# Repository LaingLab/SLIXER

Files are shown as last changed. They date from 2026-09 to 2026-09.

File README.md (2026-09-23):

<div align="center">

# Slixer

**A browser workbench for the SO-101 robot arm**

See it, program it, and let the camera tell it when.






[**Quick start**](#quick-start) ·
[**First run**](slixer/FIRST_RUN.md) ·
[**User guide**](slixer/README.md) ·
[**Vision**](slixer/VISION.md)

Slixer's 3D view of the arm beside the real SO-101, moving together

</div>

---

Slixer runs on a PC beside an [SO-101](https://github.com/TheRobotStudio/SO-ARM100) arm and serves one page to
a browser. On it:

- **A live 3D model of the arm**, built from the SO-101's own CAD, that mirrors the real arm as you move it.
- **Programs**, recorded by demonstration (move the leader arm, press R) or posed by dragging the model, then
  rehearsed on a virtual arm and played smoothly on the real one.
- **Your bench in 3D.** Import STL files of fixtures and labware, place them where they really are, and
  double-click one to send the gripper to it.
- **The camera**, with [Ultralytics](https://github.com/ultralytics/ultralytics) YOLO detecting and outlining
  what it sees on your GPU, including open-vocabulary YOLOE ("well plate, pipette tip") that needs no
  training. A program can wait until the camera sees something. Slixer also collects training pictures, with
  draft labels, for teaching a model your own things.

Three modes keep it clear what the model means: **Watch** mirrors the arm and never sends anything, **Plan**
is a virtual arm to rehearse on, and **Drive** moves the real one, speed-limited, with **STOP** (or Esc)
always a keypress away.

## How it fits together

```
 leader arm ──radio──▶ follower arm ◀──Wi-Fi──▶ PC running Slixer ◀──▶ browser
  (XIAO ESP32-C3)       (XIAO ESP32-C3)              ▲
                                                     │ camera frames
                                          Raspberry Pi + USB camera
```

The two arms teleoperate each other with no computer at all, over their own radio link. Slixer joins over
Wi-Fi: it watches the follower, and can drive it. It doesn't use lerobot's USB connection; the arms run the
firmware in this repository.

## Prerequisites

1. [uv](https://docs.astral.sh/uv/getting-started/installation/), which manages Python and the environment:
   `curl -LsSf https://astral.sh/uv/install.sh | sh`
2. **The arms**: an SO-101 leader and follower, each on a Seeed *Bus Servo Driver Board for XIAO* with a
   XIAO ESP32-C3, flashed from `so101_leader/` and `so101_follower/`. See the
   [firmware guide](so101_leader/README.md).
3. **Linux or WSL2.** Under WSL2, turn on mirrored networking so the arm's packets reach it (the firmware
   guide says how).
4. For the camera: a Raspberry Pi with a USB camera, running `pi/camera_stream.py`. For YOLO: an NVIDIA GPU
   with a recent driver (CUDA 13). Without one it runs on the CPU, slowly.

## Quick start

```bash
git clone https://github.com/LaingLab/SLIXER.git
cd SLIXER
uv sync --extra vision      # or plain `uv sync` without YOLO: the extra brings PyTorch, a few GB
uv run slixer/run.py        # then open http://localhost:8000
```

On the camera Pi: `uv run pi/camera_stream.py`. Then tell Slixer where it is, once:
`uv run slixer/run.py --camera <the Pi's address>`.

[**FIRST_RUN.md**](slixer/FIRST_RUN.md) walks through the first session in order: flashing, lining the
model up with your arm, a first program, and the camera.

> **Keep `--extra vision` on every `uv sync`.** A plain `uv sync` makes the environment match the lockfile
> exactly, so it removes PyTorch and Ultralytics again. `uv run` never removes anything.

## Documentation

| | |
| --- | --- |
| [slixer/FIRST_RUN.md](slixer/FIRST_RUN.md) | the first session, step by step |
| [slixer/README.md](slixer/README.md) | the user guide: modes, programs, parts, camera, lining up |
| [slixer/VISION.md](slixer/VISION.md) | YOLO models, open-vocabulary detection, and training your own |
| [so101_leader/README.md](so101_leader/README.md) | the arms' firmware: wiring, flashing, Wi-Fi, calibration |
| [CHANGELOG.md](CHANGELOG.md) | what's changed |

## What's in here

| folder | |
| --- | --- |
| `slixer/` | the app: a FastAPI server and the page it serves (three.js) |
| `so101_leader/`, `so101_follower/` | firmware for the two arms' XIAO ESP32-C3 boards |
| `pc/` | Python for your own code: `so101_link.py` talks to the arm, `camera_client.py` receives the camera |
| `pi/` | the camera streamer, for the Raspberry Pi |

## Safety

Slixer moves a robot. It's a beta, so go gently the first time it drives your arm.

- **STOP** (or **Esc**, which works even while you're typing) ends a program, drops anything still on its
  way, and holds the arm where it actually is. Switching to **Watch**, or closing every Slixer tab, lets go
  of it; switching to **Plan** keeps holding it.
- In **Drive**, moves are speed-limited and held to the range the arm was calibrated over. Drive waits for
  a follower that says it's ready, and a program waits for the arm: it pauses while the arm is out of
  touch, and stops, holding it, if the arm can't get where it's sent.
- **If the page loses Slixer**, it says so, and until it reconnects it can't send anything, STOP included.
  A STOP pressed meanwhile is sent the moment it's back; if the arm must stop sooner, switch off its power.
- **Parts are drawn, not felt.** The arm doesn't know an imported part is there, and will drive through it.
- **The page is served to this PC only**, unless you start it with `--host 0.0.0.0`, and only Slixer's own
  page can drive the arm, not another website open in the same browser. The arm's Wi-Fi link has no
  password of its own: anything on the same network can send it poses. Keep the arm on a network you
  trust. See [SECURITY.md](SECURITY.md).

## Development

```bash
uv run pytest               # about 160 tests, two minutes, no hardware needed
```

The tests run against an imitation follower that runs the firmware's own logic (`slixer/tests/fake_follower.py`)
and an imitation camera (`slixer/tests/fake_camera.py`), on ports the real arm never uses. The YOLO tests run
when the vision extra is installed and the models are downloaded, and are skipped otherwise.

## Licence and credits

MIT, © 2026 Laing Lab. See [LICENSE](LICENSE).

- The SO-101 model (URDF and meshes) is [TheRobotStudio/SO-ARM100](https://github.com/TheRobotStudio/SO-ARM100),
  under the Apache License 2.0: see [slixer/assets/so101/](slixer/assets/so101/).
- [three.js](https://threejs.org), vendored in `slixer/web/vendor/`, is MIT.
- The vision extra installs [Ultralytics](https://github.com/ultralytics/ultralytics), which is AGPL-3.0 (as are
  its YOLO weights). It isn't part of this repository, and the rest of Slixer runs without it.

If Slixer helps your research, please cite it: see [CITATION.cff](CITATION.cff).

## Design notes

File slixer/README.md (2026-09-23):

# Slixer

A 3D model of your SO-101, the camera beside it, and a place to write what it should do — in one page in
a browser. The model is the real SO-101 geometry; its six joints are your six servos.

```bash
uv run slixer/run.py                          # then open http://localhost:8000
uv run slixer/run.py --camera 192.168.1.50    # tell it where the camera Pi is (remembered after that)
```

`./slixer/start.sh` does the same from any folder. New here? Read [FIRST_RUN.md](FIRST_RUN.md): it walks
through the first session in order.

## Three modes

The switch at the top right decides what the model on screen *means*, and the edge of the view is
coloured so you can't mistake which one you're in.

| mode | the model is | sends to the arm | edge |
| --- | --- | --- | --- |
| **Watch** | a mirror of the real arm | never | none |
| **Plan** | a virtual arm you pose and rehearse on | never | blue |
| **Drive** | what you are telling the real arm | yes | orange |

**Watch** is where it starts, and where you teach by demonstration: move the leader by hand, the model
follows, press **record pose**. Nothing you do in Watch moves anything.

**Plan** is where programs get written. The model comes loose from the arm: drag the orange handle,
use the sliders, double-click a part, play a program — the real arm stays exactly where it is, drawn as a
blue ghost so you can see it. Coming from Drive, Slixer goes on holding it there until you switch to Watch.
Plans are still held to the arm's own calibrated joint limits.

**Drive** moves the real arm. Switching in never makes it jump (it starts from where the arm is),
commands walk at up to 90°/s rather than snapping, and everything is held to the range the arm was
calibrated over. **STOP** or **Esc** — which works even while you're typing — ends the program, drops
any move still on its way, and **holds the arm where it actually is**, still in Drive. Switching to
**Watch** is how you let go of it: the arm then freezes, or, with the leader on, glides back to the
leader. Closing every Slixer tab lets go too. Dragging the orange handle only ever bends the arm on from
the pose it's in — it never refolds it — and lining the model up in Setup is refused while driving, since
it would move the arm.

Drive waits for the follower to say it's ready: not while it's checking itself after a fault, recording
its ranges, or without a calibration. If it stops taking poses while you drive, Slixer stops sending,
goes back to Watch, and says why. If the page loses its connection to Slixer, a banner says so: until it's
back, the page can't send anything, STOP included. A STOP pressed meanwhile is sent the moment it
reconnects, but if the arm must stop sooner, switch off its power.

## Programs

A program is a list of steps: **move**, **wait**, **gripper**, and **wait for** (until the camera sees
something). New steps go in after the selected one. Select a move and it's drawn in amber — see where it
goes without going there. Double-click a move (or press **go there**) to send the model there in Plan,
or the arm in Drive. **set to current pose** re-records a step. **▶ from here** plays from the selected
step. Programs save to `slixer/programs/` as readable JSON.

In Drive, a program waits for the real arm. A move is over when the arm has got there, not when the model
has, so the next step starts from where the arm really is. If the arm drops out of touch the program
pauses, and carries on smoothly once it's back; if the arm gets no closer for 3 seconds (something in its
way, or a pose it can't reach), the program stops and holds the arm where it is.

**Moves store the arm's own numbers** — five joint angles in degrees from the middle of each joint's
calibrated travel, plus the gripper in percent: the same numbers the leader prints on its serial port.
Not the 3D model's angles. That means re-lining the model up in Setup can never change what a saved
program does to the arm.

Keys: **R** records a pose from any tab. On the Program tab, **↑/↓** select, **Delete** removes a step.

## Parts

The **Scene** tab imports STL files — the bench, a fixture, the box you pick from. Put each where the real
one sits (drag it, or type millimetres; **sit on the floor** drops it flat, whichever way it's turned).
Then, in Plan or Drive, **double-click any part's surface** and the gripper reaches for it, stopping a set
distance short along the surface — press R and that's a waypoint.

CAD and slicers export in millimetres; the model is in metres. Anything implausibly large is read as
millimetres and scaled, and the panel says so. **Parts are drawn, not felt**: the arm doesn't know they
exist and will drive straight through one.

## Camera and models

The Camera tab shows the Pi's stream exactly as it arrives. Give it the Pi's address once; it's
remembered. **camera** (top right of the view) floats it over the model; drag to move, pull the corner to
resize.

A YOLO model can run on the picture, on this PC's GPU, in a process of its own: everyday things,
**anything you type** (open-vocabulary YOLOE: "well plate, glove"), or a model you've trained on your own
things. What it finds is outlined on the picture, and a program's **wait for** step can wait for any of
those names. The Camera tab also collects training pictures, with draft labels, for training your own.
It needs the vision extra (`uv sync --extra vision`). All of it is in **[VISION.md](VISION.md)**.

## Setup: lining the model up

The URDF has its own zero for each joint, and which way your servos count depends on how they were
assembled — so the first time, the model may turn some joints the wrong way. The Setup tab shows each
joint's reading from the arm beside the model's, live. Move a joint by hand: **flip** any that turn the
wrong way, **offset** any that sit at an angle, then **save**. Changes show at once but are only kept
when you press save.

## The leader arm and Drive

The leader can stay powered while Slixer drives. Slixer's poses carry a marker saying they come from a
program, and the follower gives them the arm while they keep coming, holding the leader back. A quarter
of a second after Slixer stops sending (you switch to Watch), the arm glides back to the leader. So you
can teach with the leader, play, and carry on teaching, without powering anything down. It follows that
grabbing the leader doesn't take over from a running program: **STOP** does.

That needs the follower firmware in this repository (protocol 2, which the follower reports in its
status). With older firmware, the leader and Slixer fight over the arm, so power the leader down before
Drive. Either way, if the arm stops following what Slixer tells it, a red banner says so.

## On the network

The default is localhost only: this page can move a robot. `--host 0.0.0.0` opens it to the lab, with no
login. Either way, only Slixer's own page can drive the arm. A browser will connect to Slixer for any
website that asks, so Slixer refuses a connection from any other site, and any request addressed to a
name it doesn't answer to. IP addresses and this PC's own name work; `--allow-host NAME` adds another,
such as a DNS alias.

The arm's own link is plain UDP on port 50101 with no password: anything on the same network can send it
poses, so keep it on a network you trust. Under WSL the arm's UDP only arrives with mirrored networking on.

## Tests

```bash
uv run pytest     # ~160 tests, about two minutes, no hardware
```

They run against `tests/fake_follower.py`, which runs the follower firmware's own logic (both the old and
the new), and `tests/fake_camera.py`, in a throwaway data folder on ports the real arm never uses. The
YOLO tests run when the vision extra is installed and the models are downloaded, and are skipped
otherwise. `--data DIR` and `--arm-port N` do the same for a hands-on session with no arm:

```bash
uv run slixer/tests/fake_follower.py --listen 50198 --report-to 50199 &
uv run slixer/tests/fake_camera.py --port 50113 &
uv run slixer/run.py --arm-port 50199 --camera 127.0.0.1 --camera-port 50113 --port 8001 --data /tmp/slixer-try
```

## The pieces

| file | what it does |
| --- | --- |
| `run.py`, `start.sh` | start everything |
| `server.py` | the page, the camera, the live link |
| `session.py` | the only thing that sends to the arm: modes, one loop, all the safety rules |
| `kinematics.py` | reads the URDF; forward kinematics and the IK behind dragging and reaching |
| `mapping.py` | model angles ↔ the arm's own numbers |
| `program.py` | steps, and how a move is played out over time |
| `scene.py` | imported parts |
| `vision.py` | the model's settings → what a program can wait for |
| `detection.py`, `yolo_worker.py` | the YOLO model, in a process of its own |
| `dataset.py`, `train.py` | training pictures; training your own model |
| `settings.py`, `paths.py`, `version.py` | what's remembered, and where; which version this is |
| `web/` | the page; `three.js` is vendored so it works without internet |

The model is from [TheRobotStudio/SO-ARM100](https://github.com/TheRobotStudio/SO-ARM100)
(`Simulation/SO101`, Apache-2.0: see `assets/so101/`); `bake_meshes.py` turns its STLs into what the page
loads.

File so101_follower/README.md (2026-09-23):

# SO-101 wireless teleoperation, two XIAO ESP32-C3 boards

The leader arm's XIAO reads its six joints 50 times a second and broadcasts them by radio (ESP-NOW). The
follower arm's XIAO drives its servos to match. No computer, no network, no pairing: the two boards find
each other by themselves, and either can be restarted at any time.

Each XIAO plugs into its arm's Seeed *Bus Servo Driver Board for XIAO*, which powers it from the arm's own
supply. Calibration is read from the servos at every power-up (lerobot-calibrate stores it there), so
recalibrating never needs a re-flash. Joint mapping matches `lerobot-teleoperate` to within one encoder step.

## 1. Calibrate first

Once a board is switched to XIAO mode, lerobot on the PC can't reach that arm until you switch it back
(section 9). Do any `lerobot-calibrate` runs before converting. For the "middle" step put every joint
mid-range, and push each joint all the way to both stops during the sweep.

## 2. Switch both driver boards to XIAO mode

On each board:

1. Pull off the 2-pin **jumper cap** on the front.
2. On the back, open the solder jumpers **JP1** and **JP2**: no continuity between each pair of pads.
   (Early boards have two small resistors, R12 and R18, there instead: remove them.)
3. Solder headers to the XIAO and plug it in, USB-C end matching the outline printed on the board.

In USB mode the board's USB chip sits on the same D6/D7 wires as the XIAO, and the two fight over the line.

## 3. Flash

Arduino IDE 2, **Tools > Board > esp32 > XIAO_ESP32C3**, USB CDC On Boot enabled (the default).

- Open `so101_leader/so101_leader.ino`, select the leader's XIAO port, Upload.
- Open `so101_follower/so101_follower.ino`, select the other XIAO port, Upload.

The two sketches share the same headers; the folder decides which board does what. Built and checked with
esp32 core 3.3.8 and 3.3.12. For Wi-Fi, set it up first (section 7); without it the boards use their direct
radio link only, which is all teleoperation needs.

## 4. Use

Power both arms, in any order. Within a second or two the follower glides to the leader's pose and then
tracks it. Nothing moves until the follower has checked its own arm and is receiving the leader's pose.

The follower has no built-in LED. Wire one from **D10** through a ~330 ohm resistor to GND for status:

| LED | Meaning |
|---|---|
| slow blink (1 Hz) | arm checked, waiting for the leader |
| medium blink | gliding to the leader's pose |
| steady on | following |
| fast blink | leader data stopped: holding its pose, torque on |
| repeating blink count | a problem: 1 = no reply from a servo, 2 = no usable calibration, 3 = a joint outside its range, 4 = torque refused |

The follower holds its pose while the leader is off. Switch the follower off first, or support the arm.

Wrist roll is the one joint that can reach the encoder's wrap point: past about half a turn from its
calibration orientation the follower stops at its limit instead of spinning round.

## 5. Watching what happens

Open the Serial Monitor on the **leader** (any baud rate). It prints its own state and the follower's,
which the follower reports over the radio every 2 seconds:

```
[leader] follower reporting, 1500 poses sent, 15 follower reports, 0 read failures | deg: ...
[follower] following | 98 poses received
```

This matters because the follower's board feeds its XIAO from the arm's supply, which fights the PC's USB:
with 12 V applied, the follower's own USB port usually won't enumerate. The leader's board runs from 5 V and
doesn't have that problem.

## 6. Re-recording a joint's travel without a PC

lerobot-calibrate writes each joint's travel into the servos, and the servos enforce it: a joint that was
swept too little during calibration can't move beyond what was recorded. You can redo the sweep from the
**leader's** Serial Monitor, with no soldering and no lerobot. Homing offsets (the joint zero points) are
left alone, so this fixes a bad range without redoing a full calibration.

| Key | Effect |
|---|---|
| `h` / `H` | centre the arm on the pose it is in now (leader / follower) |
| `r` / `s` | start / save a sweep of the **leader's** arm |
| `R` / `S` | the same for the **follower's** arm, sent over the radio |
| `x` / `X` | cancel |
| `?` | list the keys |

**Centring (`h`/`H`) is only needed when a joint's travel crosses the encoder's 0/4095 seam**, which shows
up as that joint sweeping nearly 4095 steps while the others sweep about 2200. Such a sweep is refused when
you save it, and a range like that already in a servo is reported at start-up (see Troubleshooting), rather
than aiming the joint at a middle it can't reach. Hold every joint near the middle of its travel, press
`h`, then sweep and save. Centring opens the limits right up until you save a
sweep, so if you power off in between, the arm reports no usable calibration and you simply redo it.

The servos only keep new ranges through a power cycle if their EEPROM write-lock is clear, so saving
clears it, writes, reads the values back, and locks again. Power-cycle once afterwards to confirm: the arm
should still report `arm ready`.

Type the key and press Enter. **Support the follower before `H` or `R`**: both switch its torque off
first, so it goes limp (the log says `torque off: support the arm`). While recording, that arm's torque
stays off and the leader stops sending poses, so the follower holds still instead of mirroring the sweep.
Move **every** joint to both of its stops, then save. A sweep that missed a joint, or crossed the seam, is
refused rather than saved, and the recording carries on: sweep again and save, or cancel. After a save the
arm re-checks itself, so the log tells you whether it took.

## 7. Putting the arms on Wi-Fi (for a PC to drive them)

In **both** sketch folders, copy `wifi_config.example.h` to `wifi_config.h`, fill in your network's name
and password, and re-flash. (`wifi_config.h` is ignored by git, so the password stays on your machine.)
Each board then prints `link up (radio + wifi)` and carries the same packets over both paths: the direct
radio link between the boards, and UDP for anything else on the network. Without `wifi_config.h`, or
with the name left empty, the boards use the radio only.

With Wi-Fi up, a PC anywhere the network reaches can watch the arm and drive it -- with
[Slixer](../slixer/README.md), or from your own code using `pc/so101_link.py`:

```
python pc/so101_link.py            # watch the arm: state, joint angles, gripper
python pc/so101_link.py --hold     # hold it where it is, proving the control path
```

No addresses to configure: the arm announces itself once a second and the script learns where it is.
Targets are joint angles measured from the middle of each joint's own travel, the same units the leader
sends. A program's poses are marked as coming from a program, and while they keep coming the follower
holds the leader back; a quarter of a second after the program stops, the leader has the arm again. So
grabbing the leader does **not** take over from a running program -- stopping the program does. With no
leader powered, stopping leaves the arm frozen in place rather than limp.

Press **W** in either board's Serial Monitor to list the networks it can hear, with their signal strength:
the quickest way to tell a wrong password from a board that can't hear the network at all.

**Under WSL**, add this to `C:\Users\<you>\.wslconfig` and run `wsl --shutdown`, otherwise packets from
the arm can't reach it (it also detaches any usbipd devices, so re-attach them afterwards):

```
[wsl2]
networkingMode=mirrored
```

Running the script from Windows instead needs no configuration at all.

## 8. Radio range

The XIAO ESP32-C3 depends on the **external antenna** that came in its box: plug one into the U.FL socket
on each board, and keep it clear of the arm's metalwork rather than lying against a bracket. Without it,
range is poor.

The firmware sends at the chip's maximum power and uses Espressif's Long Range PHY at 250 kbps, which is
far more robust than ordinary Wi-Fi rates. **Both boards must run the same firmware version for this** — a
board in long-range mode and one without it cannot hear each other at all.

Still short? Change `kFallbackChannel` in `link.h` (1, 6 and 11 are the usual choices), re-flash both, and
pick one your Wi-Fi router isn't sitting on.

## 9. Back to lerobot on the PC

Unplug the XIAO, re-bridge JP1 and JP2 with solder, and refit the jumper cap. Plug the XIAO back in only
after re-opening them.

## Troubleshooting

- **`no reply from servo N`**: arm power, board not in XIAO mode (JP1/JP2, jumper cap), XIAO orientation, or
  the 3-pin servo lead. To rule out the XIAO itself, take it off the board, join **D6 to D7** with a wire,
  power it by USB and type **`L`** in its Serial Monitor: it sends six bytes and checks they come back.
- **`outside its calibrated range`**: move that joint by hand toward the middle; it re-checks every second.
- **`no usable calibration in servo N`**: that joint's recorded travel is too small to use. Re-record it
  with the keys in section 6, or recalibrate with lerobot.
- **`... has no range yet (limits 0-4095)`**: the servo's limits are wide open, as centring leaves them.
  Record a range with the keys in section 6, or recalibrate with lerobot.
- **`... is nearly a full turn: it crosses the encoder seam`**: that joint's range was recorded across the
  0/4095 seam, so its middle is somewhere it can't reach. Centre (`h`/`H`) and record it again (section 6).
- **The IDE offers "Ozobot circuit kit" instead of the XIAO**: its board entry claims the same generic
  Espressif USB id, so auto-detect matches it first. Select **Tools > Board > esp32 > XIAO_ESP32C3** by
  hand and ignore the mismatch warning; the sketch refuses to build for the wrong chip anyway.
- **Nothing from the follower in the leader's log**: check the follower has power, is flashed with
  `so101_follower`, and that both boards print `radio up` at start-up.
- **The follower joins Wi-Fi with the arm's 12 V unplugged, but not with it on**: noise from the servo
  supply is drowning its Wi-Fi receiver. Press **W**: hearing *no* networks at all with the 12 V on, and
  yours with it off, confirms it. (The board-to-board radio keeps working, because its long-range mode is
  far more robust than Wi-Fi.) Move the antenna away from the servo board and its power wiring, add
  decoupling at the XIAO or ferrites on the power leads, or try a quieter supply.

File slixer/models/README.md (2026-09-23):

# Models

YOLO weights live here. None are in the repository: the stock ones (`yolo26s-seg.pt` and the rest) download
here the first time they're picked in the Camera tab, and `slixer/train.py` copies models you train here too.
Any `.pt` file put here shows up in the Camera tab's list. See [VISION.md](../VISION.md).

The stock weights are Ultralytics', under the AGPL-3.0 (or an Ultralytics Enterprise licence).

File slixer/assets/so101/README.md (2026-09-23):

# The SO-101 model

`so101.urdf` is `Simulation/SO101/so101_new_calib.urdf` from
[TheRobotStudio/SO-ARM100](https://github.com/TheRobotStudio/SO-ARM100), unchanged apart from its name
(upstream commit `385e8d7c68e2`). The meshes Slixer shows, in `slixer/web/models/`, were made from that
model's STL files by `slixer/bake_meshes.py`: each link's meshes merged into one and simplified.

Both are the work of TheRobotStudio, used under the Apache License 2.0 (`LICENSE`, beside this file).

The original STLs aren't included: they're 16 MB, and only needed to re-bake the meshes. To do that, put
upstream's `Simulation/SO101/assets/` folder here as `assets/` and run `python slixer/bake_meshes.py`.

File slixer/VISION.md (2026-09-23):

# Vision: detecting and outlining things

Slixer can run Ultralytics YOLO models on the camera, on this PC's GPU. On an RTX 4090 that's about 14 ms
a picture for segmentation, so it keeps up with the camera with room to spare. What a model finds is
outlined on the picture, and its names count for a program's **wait for** steps.

Everything here is on the **Camera** tab.

## How it's set up

Ultralytics and PyTorch are an optional extra, because they're a few gigabytes:

```bash
uv sync --extra vision
```

Keep `--extra vision` on every `uv sync` after that: a plain `uv sync` makes the environment match the
lockfile exactly, which removes them again. On Linux, PyTorch comes as its CUDA 13 build, which needs a
recent NVIDIA driver; without a usable GPU the models run on the CPU, slowly.

The model runs in a **process of its own**, so the arm can't be affected. Slixer's control loop runs 50
times a second in the main process; a model loading, a slow picture, or a CUDA error in the model's
process can't delay it or crash it. If the model's process dies, the Camera tab says why and the arm
carries on.

Ultralytics asks for the full `opencv-python`. Slixer uses `opencv-python-headless` (the same OpenCV
without a desktop's GUI libraries), and the two can't be installed together without overwriting each
other's files, so `pyproject.toml` leaves the full one out. Ultralytics works the same with either.

To upgrade Ultralytics: `uv lock --upgrade-package ultralytics && uv sync --extra vision`. To run the
models in some other environment, point `SLIXER_VISION_PYTHON` at its Python.

Models live in `slixer/models/`; stock ones download there the first time they're picked. A model of your own
goes there too: copy in its `.pt` and reload the page. Each model runs at the picture size it was trained at,
so one trained at 1280 runs at 1280.

## Three kinds of model

| model | finds | when to use it |
| --- | --- | --- |
| `yolo26s-seg.pt` (n, s, m) | the 80 everyday COCO things — person, cup, bottle, … — outlined | trying things out |
| `yoloe-26s-seg.pt` | **whatever you type**: "well plate, pipette tip, glove" — outlined | your own things, today |
| `<yours>.pt` | exactly what you trained it on | once you've trained one |

`-seg` models outline what they find; the others only box it. The `yoloe-…-pf` model has a large built-in
vocabulary instead of being told what to look for.

A **semantic** model (one trained from `yolo26n-sem`, on the Ultralytics Platform say) marks areas rather than
things: it gives every pixel of the picture a class. Slixer outlines each patch of a class as a find, with its
box and its middle, so it's drawn and waited for like any other. A class map carries no confidence, so
**sure enough at** doesn't change what it marks; patches smaller than a speck are left out. Classification,
rotated-box (OBB) and depth models find nothing in the picture to outline, and are refused when picked.

**Start with YOLOE.** It finds things by name with no training at all: pick `yoloe-26s-seg.pt`, type what
to look for in the box, tick **run**. Whether it finds a 6-well plate well enough depends on the plate and
the light — try it. Where it's good enough, you're done; where it isn't, it still makes useful draft
labels for training your own model (below). Changing the words takes a moment, not a restart.

**sure enough at** is the confidence below which a find is ignored. Higher means fewer false alarms and
more misses.

## Teaching a model your own things

When a stock or open-vocabulary model isn't reliable enough, train one. The loop:

**1. Collect pictures** — Camera tab → *Training pictures*. Name the dataset (e.g. `plates`), then press
**capture** (or **C**), or set **every 2 s** and move things about. Each picture is saved exactly as the
camera sent it, with the arm's pose at that moment. With a model running and **draft labels** ticked,
what the model saw is saved as a first draft of the labels. An unchanged scene isn't saved twice.

Aim for a couple of hundred pictures to start, varied the way the arm will really see things: different
positions, angles, lighting, clutter, the gripper in shot, partly hidden objects, and a few with none of
your things in (they teach it what *isn't* there).

**2. Correct the labels** in an annotation tool. Outlines, not boxes, for a segmentation model.

- [CVAT](https://www.cvat.ai) or [Label Studio](https://labelstud.io) (both free; run locally or online),
  or [Roboflow](https://roboflow.com) (quickest to start).
- Import `slixer/datasets/<name>/images/` with the draft labels in `labels/` (YOLO format, class names
  in `classes.txt`), fix and finish them, and export as **YOLO / Ultralytics segmentation**.
- Put the exported `labels/` back over the dataset's `labels/`, and its class list in `classes.txt`
  (one name per line, in the same order as the class numbers) — or keep the tool's export whole and
  train from its `data.yaml` (next step).

Draft labels from a stock model use its names ("cup"); rename them to yours in the tool. YOLOE drafts
already carry the names you typed.

**3. Train.** On an RTX 4090, a few hundred pictures take minutes:

```bash
uv run slixer/train.py plates                          # a dataset Slixer collected
uv run slixer/train.py ~/Downloads/export/data.yaml    # or a tool's export
```

It splits the labelled pictures 80/20 into learning and checking, trains from `yolo26s-seg.pt`, and copies
the best result to `slixer/models/plates-<date>.pt`. `--model yolo26s.pt` trains a box-only model;
`--epochs` sets how long.

**4. Use it** — reload the Camera tab, pick `plates-<date>.pt`, tick **run**.

**5. Go round again.** Run your model while capturing more pictures: its drafts are now about your things,
so each round of correcting is faster, and the next model better.

## Using what it sees

- **In a program**: `+ wait for` → type or pick a name. The step waits until the model sees that name,
  or gives up after the time you set.
- **Where**: every find carries a box, a centre and (for `-seg`) an outline, all as fractions of the
  picture, in Slixer's state (`slixer.state.vision.found` in the browser console).

Not done yet: turning a position *in the picture* into a position *for the gripper*. That needs the
camera calibrated: its lens, and where it sits relative to the arm (on the wrist, where it points changes
as the arm moves). The arm's pose saved with every training picture is the start of that; it's the
natural next step once detection is reliable.

## If something's wrong

| the Camera tab says | because |
| --- | --- |
| *Models need the vision extra* | run `uv sync --extra vision`, then restart Slixer |
| *Loading … (the first time, it downloads)* | fetching the weights: a few seconds to a minute |
| *… finds things by name: type what to look for* | YOLOE needs words in the **look for** box |
| *Stopped: …* | the model process died; the reason follows, and `vision-worker.log` has the rest |
| *Stopped: it failed on 20 pictures in a row: …* | it loaded, but Slixer can't read what it returns; the reason follows, and `vision-worker.log` has the rest |
| *Stopped: … is a classification model* | it names a whole picture rather than finding things in it: train a detection or segmentation model |
| it runs but finds nothing | lower **sure enough at**; check the words (YOLOE) or the model |

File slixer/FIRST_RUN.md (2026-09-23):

# First run

In order. The first two steps need doing once; after that, starting Slixer is one command.

## 1. Flash both boards (once)

The [firmware guide](../so101_leader/README.md) covers the hardware side: calibrating the arms, switching
their driver boards to XIAO mode, and fitting the antennas. Then:

1. In **both** `so101_leader/` and `so101_follower/`, copy `wifi_config.example.h` to `wifi_config.h` and
   put your network's name and password in it. (`wifi_config.h` stays out of git.)
2. Open each sketch in the Arduino IDE 2 and upload it: `so101_follower` to the follower's XIAO,
   `so101_leader` to the leader's. Pick the board by hand each time, **Tools → Board → esp32 →
   XIAO_ESP32C3**: the IDE likes to guess "Ozobot circuit kit", which is the wrong chip.

Power both arms. The follower should glide to the leader's pose and follow it. The leader's Serial Monitor
shows both boards' state every two seconds, the follower's for example:

```
[follower] following on radio + wifi (192.168.1.135, -41 dBm) | 812 poses (0 stale ignored, 0 leader poses held back for a program) | goals: ...
```

If it says `radio only (...)` instead, the bracket says why. Press **W** in either board's Serial Monitor to
list the networks it can hear. A follower that hears *no* networks at all while the arm's 12 V supply is
on, but does with it off, is being drowned by supply noise: move its antenna away from the servo board and
its power wires.

## 2. Install and start

```bash
git clone https://github.com/LaingLab/SLIXER.git
cd SLIXER
uv sync --extra vision
```

On the camera Pi (with its own copy of the repository): `uv run pi/camera_stream.py`

On the PC:

```bash
uv run slixer/run.py --camera 192.168.1.50     # your Pi's address: only needed the first time
```

Open **http://localhost:8000**. Top left should read something like **following the leader arm** (or
**holding**) and **camera**. If the arm pill says **no arm on the network**, the follower isn't on Wi-Fi
(step 1), or this PC can't hear it: under WSL2, turn on mirrored networking (see the firmware guide), and
`uv run pc/so101_link.py` prints whatever arrives.

## 3. Line the model up (about five minutes, once)

**Setup** tab, in **Watch**. Move one joint of the leader at a time; the follower copies it, and the model
should too.

- A joint turning the **wrong way**: **flip**.
- Turning the right way but **sitting at an angle**: type an **offset** until it matches.
- **save**.

The **arm** column is the arm's own reading; the **model** column is the model's. Programs don't depend
on any of this (they store the arm's own numbers), so you can record programs before lining up if you
like, but dragging the gripper and reaching for parts need it right.

## 4. A first program, by demonstration

1. **Program** tab, **Watch** mode.
2. Move the leader to a pose. Press **R**. Move, **R**. Three or four poses.
3. **+ gripper** between them if you like. Select any move to see it in amber.
4. Switch to **Plan** and press **▶ play**: it rehearses on the virtual arm. The real one doesn't move.
5. Hand near **STOP** (or Esc). Switch to **Drive**, press **▶ play**. The follower runs it. **STOP**
   holds the arm where it is; switch to **Watch** to let go of it.
6. **save** it with a name.

You can leave the leader on: it's held back while Slixer drives, and has the arm back a quarter of a second
after you switch to Watch. If the arm stops following, a red banner says so, with the likely reason.

## 5. Things to try

- **Plan mode, orange handle**: drag the gripper around; the sliders pose each joint.
- **Scene**: drop in an STL of something on your bench, place it, then (in Plan) **double-click its
  surface**: the gripper goes there, 20 mm short. **R** records it. A part that comes in standing on its
  edge (exported Y-up) needs **lie flat**.
- **Camera → Model**: pick `yoloe-26s-seg.pt`, type what to look for ("well plate, pipette tip"), tick
  **run**: it outlines them with no training. Or `yolo26s-seg.pt` for everyday things. A program's
  **+ wait for** step can then wait for any of those names. [VISION.md](VISION.md) has the rest, including
  training a model on your own things.
- **camera** (top right of the 3D view) floats the picture over the model; drag it about, pull its corner.

## If something's wrong

| you see | likely because |
| --- | --- |
| a joint of the model turns the wrong way | not lined up yet: Setup, flip |
| red banner "the arm isn't following" | the leader is on and the follower has older firmware (flash it), or something is blocking the arm |
| arm pill "only the leader is on Wi-Fi" | the follower isn't on Wi-Fi; Drive is refused, since it couldn't hear you |
| Drive refused: "no arm to drive" | no follower reports reaching this PC |
| Drive refused: "the arm isn't ready" | the follower is checking itself after a fault, or recording ranges: the message says which |
| "stopped sending to the arm" | the follower stopped taking poses while you drove it; Drive again once it's ready |
| a program stops: "the arm didn't get there" | something is in the arm's way, or the pose is out of its reach |
| banner "Lost the connection to Slixer" | Slixer has stopped, or the PC is struggling; the page reconnects by itself |
| camera pill "camera not answering" | `camera_stream.py` isn't running on the Pi, or the address is wrong (Camera tab) |
| Camera tab: "Models need the vision extra" | run `uv sync --extra vision`, then restart Slixer |

## A beta

Slixer is tested end to end against an imitation follower that runs the firmware's own logic, and an
imitation camera: every mode, programs, parts, YOLO models on the GPU, training pictures, calibration and
saving. Real arms differ, in joint directions, lighting, and Wi-Fi, so go gently the first time in Drive,
and please report what you find: https://github.com/LaingLab/SLIXER/issues

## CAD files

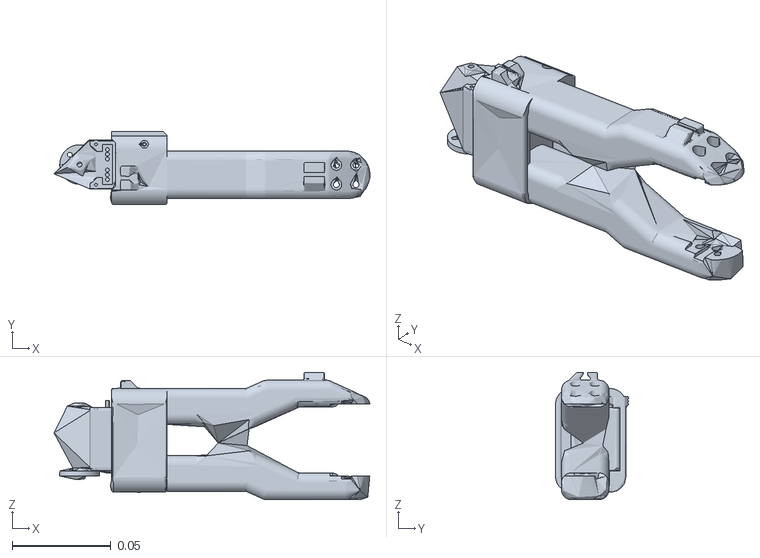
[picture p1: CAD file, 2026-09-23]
slixer/web/models/lower_arm_link.stl
0.16 x 0.0369 x 0.0644

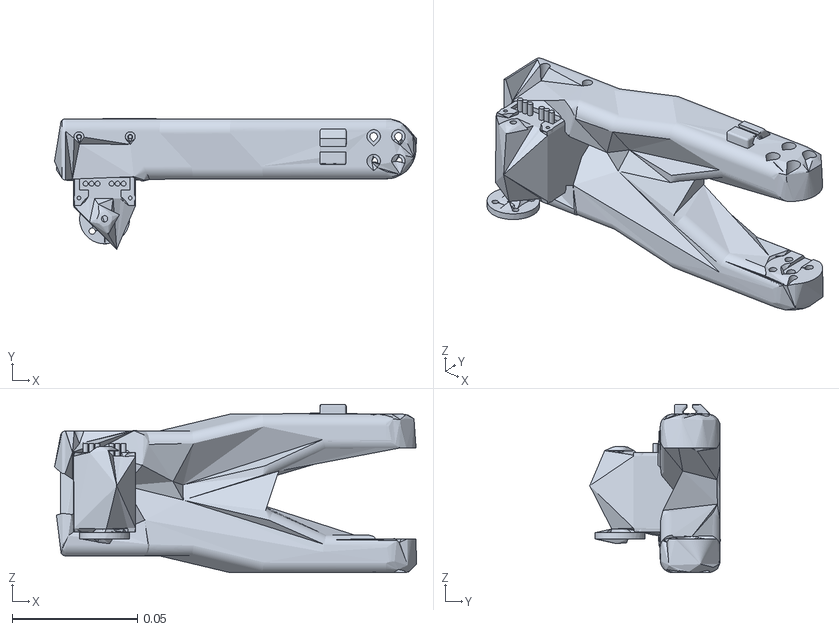
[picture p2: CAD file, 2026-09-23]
slixer/web/models/upper_arm_link.stl
0.145 x 0.0522 x 0.0674

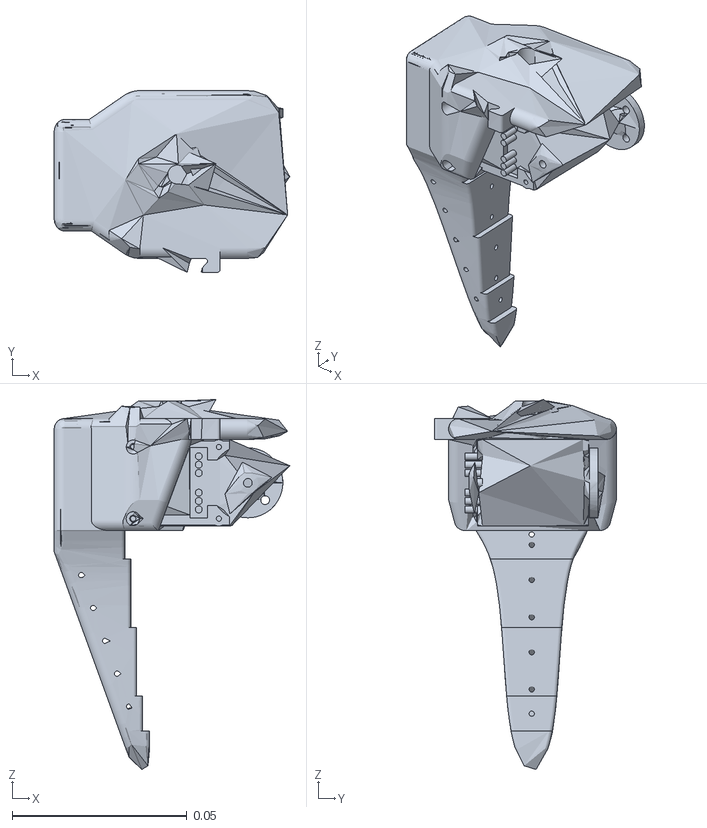
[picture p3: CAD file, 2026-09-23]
slixer/web/models/gripper_link.stl
0.0674 x 0.052 x 0.106

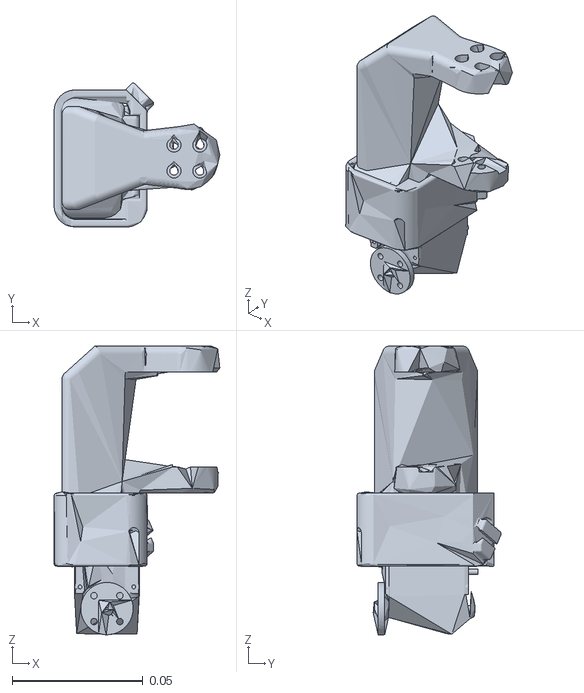
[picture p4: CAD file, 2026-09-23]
slixer/web/models/shoulder_link.stl
0.0634 x 0.0551 x 0.111

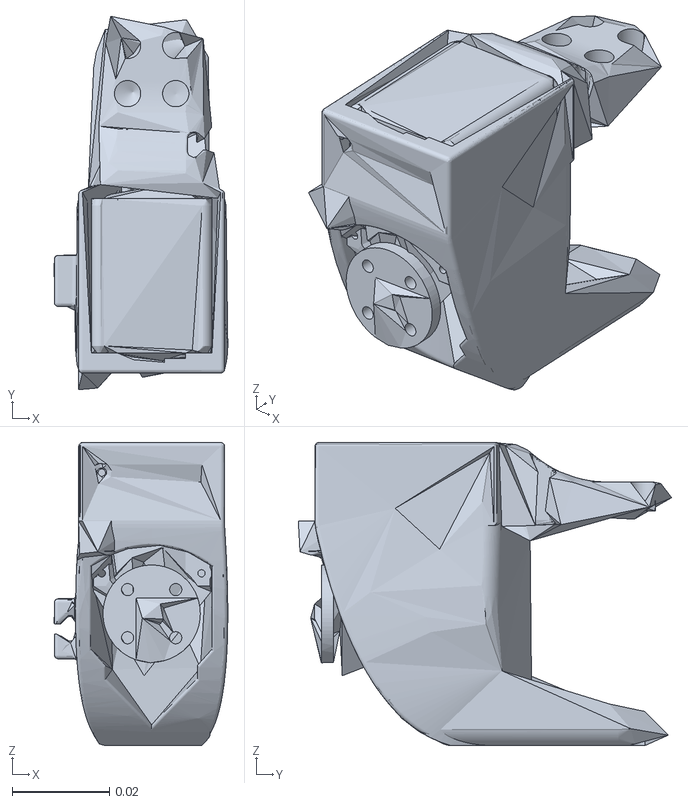
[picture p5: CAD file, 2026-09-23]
slixer/web/models/wrist_link.stl
0.0357 x 0.0768 x 0.0623

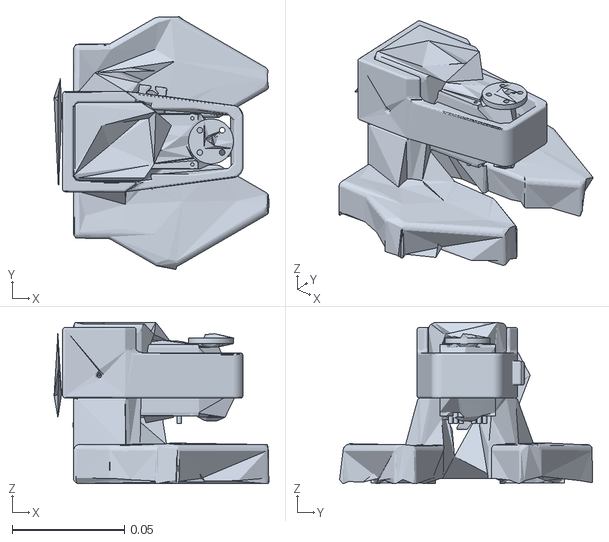
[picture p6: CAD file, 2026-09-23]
slixer/web/models/base_link.stl
0.0956 x 0.113 x 0.0718

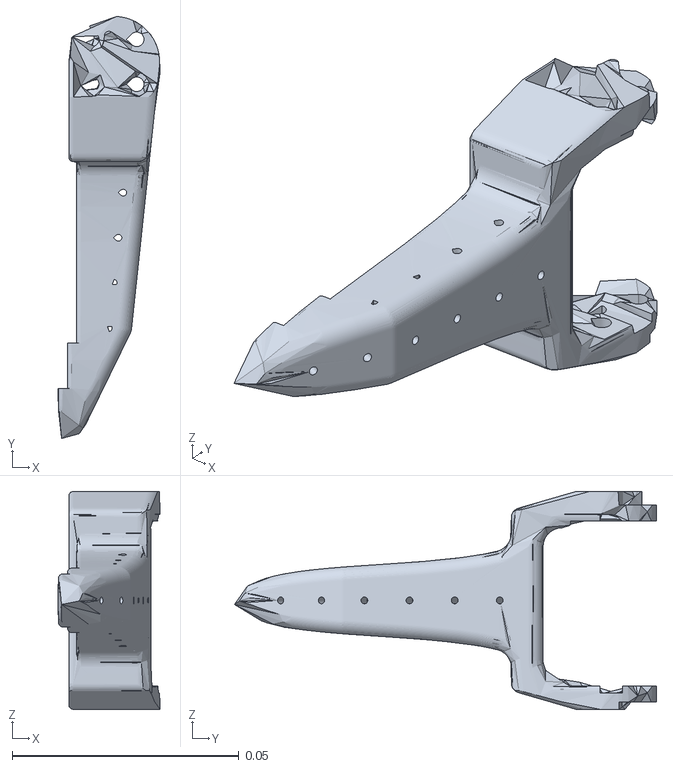
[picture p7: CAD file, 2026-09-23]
slixer/web/models/moving_jaw_so101_v1_link.stl
0.0225 x 0.093 x 0.048

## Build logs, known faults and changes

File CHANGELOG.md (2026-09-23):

# Changelog

All notable changes to Slixer are documented in this file.

The format is based on [Keep a Changelog](https://keepachangelog.com/en/1.1.0/), and this project adheres
to [Semantic Versioning](https://semver.org/spec/v2.0.0.html). Versions are written the Python way
([PEP 440](https://peps.python.org/pep-0440/)): 0.1.0b1 is 0.1.0-beta.1.

## [Unreleased]

### Added

- **Semantic segmentation models**, such as one trained from `yolo26n-sem` on the Ultralytics Platform. Each
  patch of a class the model marks is outlined as a find, and can be waited for like any other.

### Changed

- Each model runs at the picture size it was trained at, rather than always at 640.

### Fixed

- **A model Slixer can't read the results of** no longer looks as if it's running, or still loading: after
  20 pictures in a row that fail it stops, saying why. A classification, rotated-box or depth model is
  refused when it loads, and a repeated error goes in the worker's log once, not for every picture.
- "Loading … (the first time, it downloads)" only mentions downloading for a stock model not yet downloaded.

Found by a review of 0.1.0b1, each one a way the arm could move when it shouldn't, keep moving after
STOP, or be driven by the wrong page. Every fix has a test in `slixer/tests/test_safety.py`.

- **STOP** drops moves still on their way from the page, and holds the arm where it actually is, not where
  it was last told to go. STOP, changing mode and stopping a program are carried out at once, even behind
  a slow request.
- **Esc during a drag** ends the drag: neither the handle nor a held slider sends anything more.
- **A lost connection** is noticed within 3 seconds and said plainly. A STOP pressed while it's down is
  sent the moment it's back.
- **Closing the last page** lets go of the arm even if one of its tasks has failed, and one bad state
  update no longer ends the updates.
- **Importing a big STL** no longer holds up STOP: it's prepared in a process of its own.
- **Programs wait for the real arm** in Drive: a move ends when the arm gets there, the program pauses
  while the arm is out of touch, and it stops, holding the arm, if the arm gets no closer for 3 seconds.
- **Drive** waits for a follower that's ready and calibrated, and ends, saying why, if the follower stops
  taking poses.
- **Switching from Drive to Plan** holds the real arm where it is, as Plan promises, instead of letting it
  glide back to the leader. Watch lets go.
- **Other websites can't drive the arm** through your browser: Slixer answers only its own page, at its
  own names. `--allow-host` adds a name.
- **A gripper map whose shut and open are less than 5° apart** is refused. It closed the gripper in Drive.
- Firmware: the follower reports where the arm really is while it waits for the leader, and keeps checking
  its servos while it holds the arm frozen.
- Firmware: `H` and `R` switch the follower's torque off first, so support the arm. Re-centring a servo
  that was still holding a pose would send it somewhere else.
- Firmware: a sweep across the encoder's 0/4095 seam is refused rather than saved as a nearly full-circle
  range, and a range like that already in a servo is reported at start-up. A refused save keeps recording.

## [0.1.0b1] - 2026-09-22

The first public beta.

### Added

- **A live 3D model of the SO-101**, from TheRobotStudio's URDF, that mirrors the real arm as it moves.
- **Three modes.** **Watch** mirrors the arm and never sends anything. **Plan** is a virtual arm to pose
  and rehearse on, with the real arm drawn as a ghost. **Drive** moves the real arm: never with a jump,
  at up to 90°/s, and within the range the arm was calibrated over.
- **STOP** (or Esc, even while typing) ends a program and holds the arm where it is. Switching to Watch,
  or closing every Slixer tab, lets go of it.
- **Programs** of move, wait, gripper and wait-for steps: recorded by demonstration (move the leader,
  press R), or posed by dragging the model or sliding each joint. Saved as readable JSON in the arm's own
  units, so re-lining the model up can never change what a program does.
- **Parts.** Import STL files (millimetre exports are recognised and scaled), place them by dragging or by
  numbers, lay them flat, and double-click one to send the gripper to it.
- **The camera**: a Raspberry Pi's stream, in its own tab or floating over the model.
- **YOLO detection and segmentation** on the GPU, in a process of its own so the arm never waits on it:
  stock models, open-vocabulary YOLOE that finds whatever you type, or your own. A program can wait until
  the camera sees something. Installed with `uv sync --extra vision`.
- **Training pictures**, each saved with the arm's pose and draft labels from the running model, and
  `slixer/train.py` to train a model on them.
- **Setup**: line the model up with your arm (flip, offset, or set every zero from one pose), with the
  arm's and the model's readings side by side, live.
- **Firmware** for two XIAO ESP32-C3 boards: leader-follower teleoperation over ESP-NOW with no computer;
  Wi-Fi, to reach a PC; joint travel re-recorded from the Serial Monitor; and protocol 2, in which a
  program's poses take the arm from the leader while they keep coming.
- `pc/so101_link.py` and `pc/camera_client.py`, for driving the arm and reading the camera from your own
  code, and `pi/camera_stream.py`, the camera streamer.

[Unreleased]: https://github.com/LaingLab/SLIXER/compare/v0.1.0b1...HEAD
[0.1.0b1]: https://github.com/LaingLab/SLIXER/releases/tag/v0.1.0b1

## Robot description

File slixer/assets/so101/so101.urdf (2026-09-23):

<?xml version="1.0" encoding="utf-8"?>
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
<robot name="so101_new_calib">

  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
  <link name="base_link">
    <inertial>
      <origin xyz="0.0137179 -5.19711e-05 0.0334843" rpy="0 0 0"/>
      <mass value="0.147"/>
      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
    </inertial>
    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
  </link>

  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
  <link name="shoulder_link">
    <inertial>
      <origin xyz="-0.0307604 -1.66727e-05 -0.0252713" rpy="0 0 0"/>
      <mass value="0.100006"/>
      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
    </inertial>
    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
  </link>

  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
  <link name="upper_arm_link">
    <inertial>
      <origin xyz="-0.0898471 -0.00838224 0.0184089" rpy="0 0 0"/>
      <mass value="0.103"/>
      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
    </inertial>
    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
  </link>

  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
  <link name="lower_arm_link">
    <inertial>
      <origin xyz="-0.0980701 0.00324376 0.0182831" rpy="0 0 0"/>
      <mass value="0.104"/>
      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
    </inertial>
    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
  </link>

  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
  <link name="wrist_link">
    <inertial>
      <origin xyz="-0.000103312 -0.0386143 0.0281156" rpy="0 0 0"/>
      <mass value="0.079"/>
      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
    </inertial>
    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
  </link>

  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
  <link name="gripper_link">
    <inertial>
      <origin xyz="0.000213627 0.000245138 -0.025187" rpy="0 0 0"/>
      <mass value="0.087"/>
      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
    </inertial>
    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
  </link>

  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
  <link name="gripper_frame_link">
    <origin xyz="0 0 0" rpy="0 -0 0"/>
    <inertial>
      <origin xyz="0 0 0" rpy="0 0 0"/>
      <mass value="1e-9"/>
      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
    </inertial>
  </link>

  <joint name="gripper_frame_joint" type="fixed">
    <origin xyz="-0.0079 -0.000218121 -0.0981274" rpy="0 3.14159 0"/>
    <parent link="gripper_link"/>
    <child link="gripper_frame_link"/>
    <axis xyz="0 0 0"/>
  </joint>

  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
  <link name="moving_jaw_so101_v1_link">
    <inertial>
      <origin xyz="-0.00157495 -0.0300244 0.0192755" rpy="0 0 0"/>
      <mass value="0.012"/>
      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
    </inertial>
    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
  </link>

  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
  <joint name="gripper" type="revolute">
    <origin xyz="0.0202 0.0188 -0.0234" rpy="1.5708 -5.24284e-08 -1.41553e-15"/>
    <parent link="gripper_link"/>
    <child link="moving_jaw_so101_v1_link"/>
    <axis xyz="0 0 1"/>
    <limit effort="10" velocity="10" lower="-0.174533" upper="1.74533"/>
  </joint>

  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
  <joint name="wrist_roll" type="revolute">
    <origin xyz="5.55112e-17 -0.0611 0.0181" rpy="1.5708 0.0486795 3.14159"/>
    <parent link="wrist_link"/>
    <child link="gripper_link"/>
    <axis xyz="0 0 1"/>
    <limit effort="10" velocity="10" lower="-2.74385" upper="2.84121"/>
  </joint>

  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
  <joint name="wrist_flex" type="revolute">
    <origin xyz="-0.1349 0.0052 3.62355e-17" rpy="4.02456e-15 8.67362e-16 -1.5708"/>
    <parent link="lower_arm_link"/>
    <child link="wrist_link"/>
    <axis xyz="0 0 1"/>
    <limit effort="10" velocity="10" lower="-1.65806" upper="1.65806"/>
  </joint>

  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
  <joint name="elbow_flex" type="revolute">
    <origin xyz="-0.11257 -0.028 1.73763e-16" rpy="-3.63608e-16 8.74301e-16 1.5708"/>
    <parent link="upper_arm_link"/>
    <child link="lower_arm_link"/>
    <axis xyz="0 0 1"/>
    <limit effort="10" velocity="10" lower="-1.69" upper="1.69"/>
  </joint>

  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
  <joint name="shoulder_lift" type="revolute">
    <origin xyz="-0.0303992 -0.0182778 -0.0542" rpy="-1.5708 -1.5708 0"/>
    <parent link="shoulder_link"/>
    <child link="upper_arm_link"/>
    <axis xyz="0 0 1"/>
    <limit effort="10" velocity="10" lower="-1.74533" upper="1.74533"/>
  </joint>

  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
  <joint name="shoulder_pan" type="revolute">
    <origin xyz="0.0388353 -8.97657e-09 0.0624" rpy="3.14159 4.18253e-17 -3.14159"/>
    <parent link="base_link"/>
    <child link="shoulder_link"/>
    <axis xyz="0 0 1"/>
    <limit effort="10" velocity="10" lower="-1.91986" upper="1.91986"/>
  </joint>

  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 

</robot>

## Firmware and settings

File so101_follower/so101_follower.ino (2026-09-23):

// SO-101 wireless teleoperation, FOLLOWER board: a XIAO ESP32-C3 on the follower arm's Seeed Bus Servo
// Driver Board. Receives the leader's pose over ESP-NOW and drives the follower's six servos to match.
//
// Flash this folder to the follower's XIAO; flash so101_leader to the other one.
// Board: Tools > Board > esp32 > XIAO_ESP32C3, with USB CDC On Boot enabled (the default).
//
// Safety behaviour:
//  * torque stays off until all six servos answer, their calibration looks valid, every joint rests inside
//    its calibrated range, and fresh leader data is arriving;
//  * when torque comes on, the follower glides from where it is to the leader's pose instead of jumping;
//  * if leader data stops (out of range, leader switched off) it freezes in place, torque on, and glides
//    back once data returns;
//  * if its own servos stop answering or restart (power dip), it starts over from the checks.
//
// This board has no built-in LED. Wire one from D10 through a ~330 ohm resistor to GND for status at a
// glance; otherwise watch this board's state on the leader's USB, which it reports over the radio.

#include "feetech.h"
#include "link.h"
#include "ranges.h"
#include "serial_port.h"
#include "teleop_math.h"

#if !defined(ARDUINO_XIAO_ESP32C3) && !defined(ARDUINO_XIAO_ESP32S3) && !defined(ARDUINO_XIAO_ESP32C6) \
    && !defined(ARDUINO_XIAO_ESP32C5)
#error "Wrong board: pick Tools > Board > esp32 > XIAO_ESP32C3. The IDE auto-detects 'Ozobot circuit kit' for this USB id, which is a different chip."
#endif

#if !ARDUINO_USB_CDC_ON_BOOT
#error "Set Tools > USB CDC On Boot > Enabled: otherwise status messages would go out on the servo bus"
#endif

namespace {

constexpr uint32_t kPeriodMs = 20;         // 50 Hz goal updates
constexpr uint32_t kStaleMs = 250;         // no leader data for this long -> freeze
constexpr uint32_t kHealthPeriodMs = 50;   // read the servos this often while moving
constexpr uint32_t kTelemetryPeriodMs = 50;  // report position this often: a PC steering the arm needs it
constexpr int kMaxHealthFailures = 10;     // ~1 s of failed reads -> start over
constexpr float kGlideDegPerSec = 45.0f;   // speed of the start-up / resume glide
constexpr int32_t kRangeTolerance = 150;   // a joint may rest this far (~13 deg) outside its range
constexpr int32_t kNoGlideTicks = 60;      // ~5 deg: closer than this, start following without gliding
constexpr uint8_t kCheckAttempts = 8;      // calibration reads gate everything, so retry them harder
constexpr int kStatusLed = D10;            // optional external LED, on when driven high
const uint8_t kIds[teleop::kNumJoints] = {1, 2, 3, 4, 5, 6};

enum class State : uint8_t { kChecking, kWaitingForLeader, kGliding, kFollowing, kFrozen, kRecording };

SerialPort<HardwareSerial> bus_port(Serial0);
feetech::Bus bus(bus_port);
teleop::Range cal[teleop::kNumJoints];

// Latest pose, written from the radio callback and the Wi-Fi poll.
portMUX_TYPE packet_mux = portMUX_INITIALIZER_UNLOCKED;
teleop::LeaderPacket latest;
uint32_t latest_ms = 0;
bool have_packet = false;
bool latest_from_program = false;  // whether the newest accepted pose came from a program or the leader
uint32_t program_pose_ms = 0;      // when a program's pose last arrived; 0 = never
uint32_t packets = 0, poses_since_report = 0, stale_poses = 0, leader_yielded = 0;
bool following_program = false;    // which the arm is following, so that a change of hands glides

State state = State::kChecking;
uint32_t next_tick = 0, last_check = 0, last_health = 0, last_torque_check = 0, last_report = 0;
uint32_t last_telemetry = 0;
uint32_t glide_start_ms = 0, glide_ms = 1000;
int health_failures = 0;
uint8_t torque_check_joint = 0;
bool check_failed = false;              // a check has failed since the last success: LED red
uint8_t fault = teleop::kFaultNone;     // what failed, for the LED blink code and the leader's log
uint8_t fault_joint = 0;
int32_t glide_from[teleop::kNumJoints];
int32_t goals[teleop::kNumJoints];
int32_t present_pos[teleop::kNumJoints] = {0};  // last known actual positions, reported to the PC
char problem[112] = "starting up";
teleop::RangeRecorder recorder;         // driven by R/S typed into the leader's Serial Monitor
volatile uint8_t pending_command = 0;

void onLeaderPose(const uint8_t* data, int len) {
  if (len == sizeof(teleop::CommandPacket) && data[0] == teleop::kCommandMagic) {
    pending_command = data[1];  // acted on in loop(), not in the radio callback
    return;
  }
  if (len != sizeof(teleop::LeaderPacket)) return;
  const bool from_program = data[0] == teleop::kProgramMagic;
  if (!from_program && data[0] != teleop::kPacketMagic) return;
  teleop::LeaderPacket incoming;
  memcpy(&incoming, data, sizeof incoming);
  const uint32_t arrived = millis();
  portENTER_CRITICAL(&packet_mux);
  // Two senders can't share the arm: each counts its own sequence numbers, so the newest-only filter below
  // would pick between them by whose counter happens to be higher, and the arm would lurch between two
  // poses. So while a program is sending, the leader waits its turn, whichever way its packets arrive, and
  // a quarter of a second after the program stops, the leader has the arm back.
  //
  // The claim is made by a program's pose arriving, not by one being accepted: while the leader's counter
  // is ahead, the program's are the poses the filter would throw away, so waiting for an accepted one
  // would wait for ever.
  if (from_program) {
    program_pose_ms = arrived;
  } else if (program_pose_ms != 0 && arrived - program_pose_ms < kStaleMs) {
    leader_yielded++;
    portEXIT_CRITICAL(&packet_mux);
    return;
  }
  // The same pose can arrive more than once -- by radio and by Wi-Fi -- and copies can overtake each other.
  // Acting on an older one makes the arm jump back and then forward again, which reads as twitching, so
  // only accept poses newer than the last. After a gap, take whatever arrives: the sequence may have moved
  // on or restarted. And when the pose comes from the other sender, its number means nothing next to the
  // last one's.
  const uint8_t newer_by = (uint8_t)(incoming.seq - latest.seq);
  const bool other_sender = have_packet && from_program != latest_from_program;
  if (!have_packet || other_sender || arrived - latest_ms > 500 || (newer_by != 0 && newer_by < 128)) {
    latest = incoming;
    latest_ms = arrived;
    latest_from_program = from_program;
    have_packet = true;
    packets++;
    poses_since_report++;
  } else {
    stale_poses++;
  }
  portEXIT_CRITICAL(&packet_mux);
}

// Copies the newest pose and says who sent it; true if it arrived less than kStaleMs ago.
bool freshPacket(teleop::LeaderPacket* out, bool* from_program) {
  portENTER_CRITICAL(&packet_mux);
  const bool have = have_packet;
  const uint32_t at = latest_ms;
  *out = latest;
  *from_program = latest_from_program;
  portEXIT_CRITICAL(&packet_mux);
  return have && millis() - at < kStaleMs;
}

const char* stateName() {
  switch (state) {
    case State::kRecording: return "recording ranges";
    case State::kChecking: return "checking arm";
    case State::kWaitingForLeader: return "waiting for leader";
    case State::kGliding: return "gliding to leader pose";
    case State::kFollowing: return "following";
    case State::kFrozen: return "holding (no leader data)";
  }
  return "?";
}

uint8_t stateCode() {
  switch (state) {
    case State::kRecording: return teleop::kStRecording;
    case State::kChecking: return teleop::kStChecking;
    case State::kWaitingForLeader: return teleop::kStWaiting;
    case State::kGliding: return teleop::kStGliding;
    case State::kFollowing: return teleop::kStFollowing;
    case State::kFrozen: return teleop::kStFrozen;
  }
  return teleop::kStChecking;
}

// While checking, the LED repeats the fault as a blink count: 1 = no reply from a servo, 2 = no usable
// calibration, 3 = a joint outside its range, 4 = torque refused. Steady on = following.
void updateLed(uint32_t now) {
  bool on = false;
  switch (state) {
    case State::kChecking: {
      const uint32_t blinks = fault == teleop::kFaultNone ? 1 : fault;
      const uint32_t cycle = now % (blinks * 500 + 1000);
      on = check_failed && cycle < blinks * 500 && (cycle / 250) % 2 == 0;
      break;
    }
    case State::kRecording: on = (now / 60) % 2; break;          // flicker: sweep the joints
    case State::kWaitingForLeader: on = (now / 500) % 2; break;  // slow blink: looking for the leader
    case State::kFrozen: on = (now / 125) % 2; break;            // fast blink: lost the leader, holding
    case State::kGliding: on = (now / 250) % 2; break;
    case State::kFollowing: on = true; break;
  }
  digitalWrite(kStatusLed, on ? HIGH : LOW);
}

void fail(uint32_t now, const char* why) {
  if (why != problem) snprintf(problem, sizeof problem, "%s", why);
  check_failed = true;
  Serial.printf("[follower] %s\n", problem);
  state = State::kChecking;
  last_check = now;
}

// Servos present, calibration plausible, every joint resting inside its calibrated range.
bool checkArm() {
  for (int j = 0; j < teleop::kNumJoints; j++) {
    uint16_t lo, hi;
    if (!bus.read16(kIds[j], feetech::kMinPositionLimit, &lo, kCheckAttempts) ||
        !bus.read16(kIds[j], feetech::kMaxPositionLimit, &hi, kCheckAttempts)) {
      snprintf(problem, sizeof problem, "no reply from servo %d (%s): arm powered? board in XIAO mode?", kIds[j],
               teleop::jointName(j));
      fault = teleop::kFaultNoReply;
      fault_joint = j;
      return false;
    }
    cal[j].min = lo;
    cal[j].max = hi;
  }
  if (!teleop::plausibleCalibration(cal, problem, sizeof problem)) {
    fault = teleop::kFaultCalibration;
    return false;
  }
  int32_t present[teleop::kNumJoints];
  if (!bus.readPositions(kIds, teleop::kNumJoints, present, kCheckAttempts)) {
    snprintf(problem, sizeof problem, "could not read joint positions");
    fault = teleop::kFaultNoReply;
    return false;
  }
  memcpy(present_pos, present, sizeof present_pos);
  for (int j = 0; j < teleop::kNumJoints; j++) {
    if (j == teleop::kWristRoll) continue;  // turns freely; its range is the whole circle
    if (present[j] < cal[j].min - kRangeTolerance || present[j] > cal[j].max + kRangeTolerance) {
      snprintf(problem, sizeof problem, "%s is at %ld, outside its calibrated range [%ld, %ld]: move it by hand",
               teleop::jointName(j), (long)present[j], (long)cal[j].min, (long)cal[j].max);
      fault = teleop::kFaultOutOfRange;
      fault_joint = j;
      return false;
    }
  }
  problem[0] = '\0';
  fault = teleop::kFaultNone;
  return true;
}

// Turns torque on without moving anything, then glides from the present pose to the leader's.
void startGlide(uint32_t now, const teleop::LeaderPacket& packet) {
  int32_t present[teleop::kNumJoints];
  if (!bus.readPositions(kIds, teleop::kNumJoints, present, kCheckAttempts)) {
    return fail(now, "could not read joint positions");
  }
  for (int j = 0; j < teleop::kNumJoints; j++) {
    const bool ok = bus.write8(kIds[j], feetech::kAcceleration, 254) &&  // as lerobot configures it
                    bus.write16(kIds[j], feetech::kGoalPosition, feetech::encodePosition(present[j])) &&
                    bus.write8(kIds[j], feetech::kTorqueEnable, 1);
    if (!ok) {  // servos already switched on just hold where they are
      snprintf(problem, sizeof problem, "servo %d (%s) did not accept torque-on", kIds[j], teleop::jointName(j));
      fault = teleop::kFaultWriteRefused;
      fault_joint = j;
      return fail(now, problem);
    }
  }
  int32_t target[teleop::kNumJoints];
  teleop::goalsFromPacket(packet, cal, target);
  int32_t farthest = 0;
  for (int j = 0; j < teleop::kNumJoints; j++) {
    glide_from[j] = present[j];
    goals[j] = present[j];
    const int32_t d = abs(target[j] - present[j]);
    if (d > farthest) farthest = d;
  }
  health_failures = 0;
  // Already where the leader is? Just follow. Gliding every time the link hiccups would make the arm
  // stutter, and a glide is only worth its slowness when the arm has somewhere to travel.
  if (farthest < kNoGlideTicks) {
    state = State::kFollowing;
    return;
  }
  const float seconds = farthest * 360.0f / teleop::kTurn / kGlideDegPerSec;
  glide_ms = (uint32_t)(seconds * 1000);
  if (glide_ms < 500) glide_ms = 500;
  if (glide_ms > 5000) glide_ms = 5000;
  glide_start_ms = now;
  state = State::kGliding;
  Serial.printf("[follower] torque on, gliding to the leader's pose over %lu ms\n", (unsigned long)glide_ms);
}

// While torque is on: servos must keep answering, and none may have restarted (a power dip turns torque off).
void checkHealth(uint32_t now) {
  if (now - last_health < kHealthPeriodMs) return;
  last_health = now;
  int32_t present[teleop::kNumJoints];
  if (!bus.readPositions(kIds, teleop::kNumJoints, present)) {
    if (++health_failures > kMaxHealthFailures) {
      fault = teleop::kFaultNoReply;
      fail(now, "follower servos stopped answering (power?)");
    }
    return;
  }
  health_failures = 0;
  memcpy(present_pos, present, sizeof present_pos);
  if (now - last_torque_check >= 1000) {
    last_torque_check = now;
    uint8_t torque = 1;
    const uint8_t id = kIds[torque_check_joint];
    torque_check_joint = (torque_check_joint + 1) % teleop::kNumJoints;
    if (bus.read(id, feetech::kTorqueEnable, 1, &torque) && torque == 0) {
      char why[72];
      snprintf(why, sizeof why, "servo %d lost torque (power dip?), restarting", id);
      fault = teleop::kFaultNoReply;
      fail(now, why);
    }
  }
}

// Keeps the reported position true while nothing else is reading the servos. Waiting for the leader, torque
// is off and the arm can be moved by hand; anything steering the arm starts from what's reported here, and a
// stale report would have it glide the arm back to where it used to be.
void refreshPositions(uint32_t now) {
  if (now - last_health < kHealthPeriodMs) return;
  last_health = now;
  int32_t present[teleop::kNumJoints];
  if (bus.readPositions(kIds, teleop::kNumJoints, present)) memcpy(present_pos, present, sizeof present_pos);
}

// Recording and re-centring both mean moving the arm by hand, so torque goes off first. After a fault the
// servos can still be holding -- fail() deliberately doesn't let a loaded arm drop -- and re-homing a servo
// that is holding a goal would drive it somewhere else entirely.
bool torqueOff() {
  bool ok = true;
  for (int j = 0; j < teleop::kNumJoints; j++) ok = bus.write8(kIds[j], feetech::kTorqueEnable, 0) && ok;
  return ok;
}

// Typing 'L' in the Serial Monitor runs this. Take the XIAO OFF its servo board, join D6 to D7 with a wire
// and power it from USB: it proves whether this board's serial port and those two pins work at all. On the
// servo board it would always fail, because that board mutes the receive line while transmitting.
void loopbackTest() {
  const uint8_t probe[] = {0x55, 0xAA, 0x0F, 0xF0, 0x12, 0x34};
  Serial.println("[follower] loopback test: XIAO off its board, D6 wired to D7...");
  while (Serial0.available()) Serial0.read();
  Serial0.write(probe, sizeof probe);
  Serial0.flush();
  uint8_t got[sizeof probe];
  size_t n = 0;
  const uint32_t deadline = millis() + 200;
  while (n < sizeof probe && (int32_t)(millis() - deadline) < 0) {
    if (Serial0.available()) got[n++] = (uint8_t)Serial0.read();
  }
  if (n == sizeof probe && memcmp(probe, got, n) == 0) {
    Serial.println("[follower] loopback PASSED: serial port and D6/D7 are fine");
  } else {
    Serial.printf("[follower] loopback FAILED: sent 6 bytes, got %u back\n", (unsigned)n);
  }
}
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
void loop() {
  const uint32_t now = millis();
  updateLed(now);
  if (Serial.available()) {
    const int c = Serial.read();
    if (c == 'l' || c == 'L') loopbackTest();
    if (c == 'w' || c == 'W') net::scanNetworks();
  }
  if ((int32_t)(now - next_tick) < 0) {
    delay(1);
    return;
  }
  next_tick = now + kPeriodMs;
  net::poll();
  sendTelemetry(now);
  report(now);
  if (pending_command != 0) {
    const uint8_t command = pending_command;
    pending_command = 0;
    handleCommand(now, command);
  }

  teleop::LeaderPacket packet;
  bool from_program = false;
  const bool fresh = freshPacket(&packet, &from_program);

  switch (state) {
    case State::kChecking:
      if (now - last_check >= 1000) {
        last_check = now;
        check_failed = !checkArm();
        if (!check_failed) {
          Serial.println("[follower] arm ready, waiting for the leader");
          state = State::kWaitingForLeader;
        } else {
          static char last_complaint[112] = "";
          static uint32_t last_complained = 0;
          if (strcmp(problem, last_complaint) != 0 || now - last_complained > 15000) {
            snprintf(last_complaint, sizeof last_complaint, "%s", problem);
            last_complained = now;
            Serial.printf("[follower] waiting: %s\n", problem);
          }
          if (fault == teleop::kFaultNoReply) {
            Serial.println("[follower] (type L here with the XIAO off its board and D6 wired to D7 to test its serial port)");
          }
        }
      }
      break;

    case State::kRecording: {
      int32_t present[teleop::kNumJoints];
      if (bus.readPositions(kIds, teleop::kNumJoints, present)) {
        recorder.update(present);
        memcpy(present_pos, present, sizeof present_pos);
      }
      break;
    }

    case State::kWaitingForLeader:
      if (fresh) {
        if (checkArm()) {
          following_program = from_program;
          startGlide(now, packet);  // the arm may have been moved by hand while waiting
        } else {
          check_failed = true;
          fail(now, problem);
        }
      } else {
        refreshPositions(now);
      }
      break;

    case State::kFrozen:
      if (fresh) {
        following_program = from_program;
        startGlide(now, packet);
      } else {
        checkHealth(now);  // torque is on: keep checking the servos answer, and report where the arm is
      }
      break;

    case State::kGliding:
    case State::kFollowing: {
      if (!fresh) {
        state = State::kFrozen;
        Serial.println("[follower] leader data stopped: holding position");
        break;
      }
      if (from_program != following_program) {
        // A program has just taken over from the leader, or handed back to it. The two were almost
        // certainly asking for different poses, and following the new one directly would be a lunge at
        // full servo speed; glide there instead, exactly as after any other interruption.
        following_program = from_program;
        Serial.printf("[follower] %s has the arm now\n", from_program ? "a program" : "the leader");
        startGlide(now, packet);
        break;
      }
      int32_t target[teleop::kNumJoints];
      teleop::goalsFromPacket(packet, cal, target);
      if (state == State::kGliding) {
        float u = (now - glide_start_ms) / (float)glide_ms;
        if (u >= 1.0f) {
          u = 1.0f;
          state = State::kFollowing;
        }
        const float s = u * u * (3.0f - 2.0f * u);  // ease in and out
        for (int j = 0; j < teleop::kNumJoints; j++) {
          goals[j] = glide_from[j] + lroundf((target[j] - glide_from[j]) * s);
        }
      } else {
        memcpy(goals, target, sizeof goals);
      }
      bus.writeGoals(kIds, teleop::kNumJoints, goals);
      checkHealth(now);
      break;
    }
  }
}

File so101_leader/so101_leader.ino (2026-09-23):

// SO-101 wireless teleoperation, LEADER board: a XIAO ESP32-C3 on the leader arm's Seeed Bus Servo Driver
// Board. Reads the six leader joints 50 times a second and broadcasts them to the follower board over
// ESP-NOW. Only reads the servos; never enables torque or writes to them.
//
// Flash this folder to the leader's XIAO; flash so101_follower to the other one.
// Board: Tools > Board > esp32 > XIAO_ESP32C3, with USB CDC On Boot enabled (the default).
//
// Calibration is read from the servos at start-up (lerobot-calibrate stores it there), so recalibrating
// never needs a re-flash.

#include "feetech.h"
#include "link.h"
#include "ranges.h"
#include "serial_port.h"
#include "teleop_math.h"

#if !defined(ARDUINO_XIAO_ESP32C3) && !defined(ARDUINO_XIAO_ESP32S3) && !defined(ARDUINO_XIAO_ESP32C6) \
    && !defined(ARDUINO_XIAO_ESP32C5)
#error "Wrong board: pick Tools > Board > esp32 > XIAO_ESP32C3. The IDE auto-detects 'Ozobot circuit kit' for this USB id, which is a different chip."
#endif

#if !ARDUINO_USB_CDC_ON_BOOT
#error "Set Tools > USB CDC On Boot > Enabled: otherwise status messages would go out on the servo bus"
#endif

namespace {

constexpr uint32_t kPeriodMs = 20;  // 50 Hz
constexpr uint32_t kRestartAfterFailuresMs = 500;
const uint8_t kIds[teleop::kNumJoints] = {1, 2, 3, 4, 5, 6};

SerialPort<HardwareSerial> bus_port(Serial0);
feetech::Bus bus(bus_port);
teleop::Range cal[teleop::kNumJoints];
teleop::Unwrapper unwrap[teleop::kNumJoints];

teleop::RangeRecorder recorder;  // 'r'/'s' re-record this arm's joint ranges; 'R'/'S' the follower's
bool arm_ready = false;
uint8_t seq = 0;
uint32_t next_tick = 0, last_good_read = 0, last_report = 0, last_check = 0;
uint32_t sent = 0, read_failures = 0, follower_reports = 0;
uint32_t last_follower_ms = 0;
int32_t last_pos[teleop::kNumJoints];

// The follower reports itself here, so its state is readable on this board's USB while it runs headless.
void onFollowerStatus(const uint8_t* data, int len) {
  // Either size: a follower from before the version byte is still worth hearing from.
  if (len != sizeof(teleop::FollowerStatus) && len != (int)teleop::kStatusV1Size) return;
  teleop::FollowerStatus status = {};
  memcpy(&status, data, len);
  if (status.magic != teleop::kStatusMagic) return;
  follower_reports++;
  last_follower_ms = millis();
  static uint32_t last_printed = 0;
  if (last_follower_ms - last_printed < 2000) return;  // it reports many times a second; log one
  last_printed = last_follower_ms;
  Serial.printf("[follower] %s", teleop::stateText(status.state));
  if (status.fault != teleop::kFaultNone && status.joint < teleop::kNumJoints) {
    Serial.printf(": %s %d (%s)", teleop::faultText(status.fault), status.joint + 1, teleop::jointName(status.joint));
  }
  Serial.printf(" | %u poses received\n", status.poses);
}

void sendCommand(uint8_t command) {
  const teleop::CommandPacket packet = {teleop::kCommandMagic, command};
  net::send(&packet, sizeof packet);
}

// Keys typed in the Serial Monitor. Lower case acts on this arm, upper case on the follower's.
void handleKey(int key) {
  switch (key) {
    case 'w':
    case 'W':
      net::scanNetworks();
      break;
    case 'r': {
      int32_t present[teleop::kNumJoints];
      if (!arm_ready || !bus.readPositions(kIds, teleop::kNumJoints, present, 8)) {
        Serial.println("[leader] can't read this arm yet");
        return;
      }
      recorder.start(present);
      Serial.println("[leader] recording ranges: sweep every joint to both stops, then press s. Poses are not sent while recording.");
      break;
    }
    case 's': {
      if (!recorder.active()) return;
      char msg[112];
      if (recorder.save(bus, kIds, cal, msg, sizeof msg)) {
        for (auto& u : unwrap) u.reset();
        Serial.print("[leader] new ranges saved:");
        for (int j = 0; j < teleop::kNumJoints; j++) {
          Serial.printf(" %s[%ld,%ld]", teleop::jointName(j), (long)cal[j].min, (long)cal[j].max);
        }
        Serial.println();
      } else {
        Serial.printf("[leader] not saved: %s\n", msg);
      }
      break;
    }
    case 'h': {
      if (!arm_ready) {
        Serial.println("[leader] can't read this arm yet");
        return;
      }
      char msg[112];
      Serial.println("[leader] centring this arm on the pose it is in now...");
      if (teleop::setHome(bus, kIds, cal, msg, sizeof msg)) {
        for (auto& u : unwrap) u.reset();
        Serial.printf("[leader] %s\n", msg);
      } else {
        Serial.printf("[leader] not centred: %s\n", msg);
      }
      break;
    }
    case 'H': sendCommand(teleop::kCmdSetHome); Serial.println("[leader] told the follower to centre on its current pose"); break;
    case 'x': recorder.cancel(); Serial.println("[leader] recording cancelled"); break;
    case 'R': sendCommand(teleop::kCmdRecordRanges); Serial.println("[leader] told the follower to record its ranges"); break;
    case 'S': sendCommand(teleop::kCmdSaveRanges); Serial.println("[leader] told the follower to save its ranges"); break;
    case 'X': sendCommand(teleop::kCmdCancelRecording); Serial.println("[leader] told the follower to cancel"); break;
    case '?':
      Serial.println("[leader] keys (lower case = this arm, upper = follower):");
      Serial.println("[leader]   h/H centre the arm on its current mid-range pose (do this first if a joint's");
      Serial.println("[leader]       travel crosses the encoder seam), then r/R sweep, then s/S save, x/X cancel");
      break;
    default: break;
  }
}

// Pings the six servos and loads their calibration.
bool checkArm() {
  char why[112] = "";
  for (int j = 0; j < teleop::kNumJoints && !why[0]; j++) {
    uint16_t lo, hi;
    if (!bus.read16(kIds[j], feetech::kMinPositionLimit, &lo, 8) ||
        !bus.read16(kIds[j], feetech::kMaxPositionLimit, &hi, 8)) {
      snprintf(why, sizeof why, "no reply from servo %d (%s): arm powered? board in XIAO mode?", kIds[j],
               teleop::jointName(j));
    } else {
      cal[j].min = lo;
      cal[j].max = hi;
    }
  }
  if (!why[0]) teleop::plausibleCalibration(cal, why, sizeof why);
  if (why[0]) {
    static char last_complaint[112] = "";
    static uint32_t last_complained = 0;
    if (strcmp(why, last_complaint) != 0 || millis() - last_complained > 15000) {  // don't flood the log
      snprintf(last_complaint, sizeof last_complaint, "%s", why);
      last_complained = millis();
      Serial.printf("[leader] waiting: %s\n", why);
    }
    return false;
  }
  for (auto& u : unwrap) u.reset();
  Serial.print("[leader] arm ready, calibration:");
  for (int j = 0; j < teleop::kNumJoints; j++) {
    Serial.printf(" %s[%ld,%ld]", teleop::jointName(j), (long)cal[j].min, (long)cal[j].max);
  }
  Serial.println();
  return true;
}

}  // namespace
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

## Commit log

2026-09-23 Slixer 0.1.0b1: first public beta
    A browser workbench for the SO-101 robot arm: a live 3D model that mirrors
    the arm, programs recorded by demonstration and played back, imported STL
    parts to program around, and the camera with YOLO detection and
    segmentation that programs can wait on. Includes firmware for wireless
    leader-follower teleoperation on two XIAO ESP32-C3 boards.
    [base_link.stl, gripper_link.stl, lower_arm_link.stl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]
2026-09-23 CI: create arduino-cli's install folder before installing it
    The install script refuses a BINDIR that doesn't exist yet, so the firmware
    job failed on a fresh runner. Also pins arduino-cli to 1.5.1, the version the
    sketches were built with.
2026-09-23 Show Slixer and the real arm moving together in the README
    docs/arm.gif: Slixer's 3D view beside the SO-101 on the bench, following the
    same moves (720x480, 7 s).
2026-09-23 Fix the safety problems found in a review of 0.1.0b1
    Each was a way the arm could move when it shouldn't, keep moving after
    STOP, or be driven by the wrong page. Every fix has a test in
    slixer/tests/test_safety.py, and CHANGELOG.md lists them.
    - STOP drops moves still queued from the page and holds the arm where
    it actually is. STOP, mode changes and stopping a program are handled
    at once, even behind a slow request.
    - Esc ends a drag in progress. A lost connection is noticed within 3 s
    and said plainly, and a STOP pressed meanwhile is sent on reconnect.
    - Closing the last page always lets go of the arm, and STL imports run
    in a process of their own so they can't hold up STOP.
    - In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
    [fake_follower.py, helpers.py, ranges.h]
2026-09-23 Run semantic segmentation models, and say when a model can't be read
    A semantic model (one trained from yolo26n-sem, on the Ultralytics
    Platform say) gives every pixel a class instead of listing things, so
    its results have no boxes. The worker failed on every picture, while the
    Camera tab looked as if the model were running.
    - regions.py turns each patch of a class map into a find: its outline,
    box and middle, with no score, since a class map has none.
    - Each model runs at the picture size it was trained at, not always 640.
    - Classification, rotated-box and depth models are refused when they
    load, saying why.
    - A model that fails on 20 pictures in a row is stopped, saying why, and
    the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
    [fake_worker.py, test_detection.py]

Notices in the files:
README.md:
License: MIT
